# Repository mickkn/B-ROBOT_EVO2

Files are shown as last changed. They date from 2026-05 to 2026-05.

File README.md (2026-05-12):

# RCBRO - RC Based Self Balancing Robot

Based on this project:  
[Github](https://github.com/jjrobots/B-ROBOT_EVO2)  
[Thingiverse](https://www.thingiverse.com/thing:2306541)

# Introduction

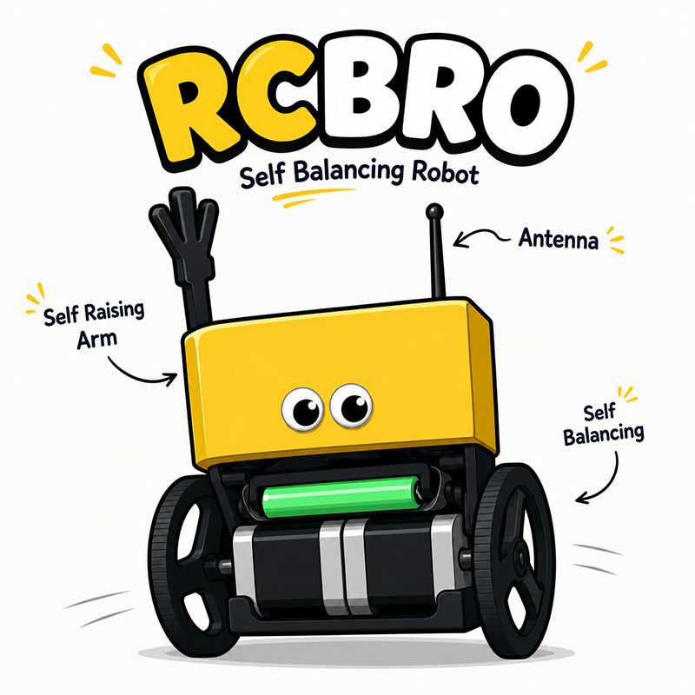
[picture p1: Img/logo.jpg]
RCBRO


RCBRO is a Radio Control Based Self Balancing Robot. It is a two-wheeled robot that can balance itself using a 
gyroscope and accelerometer. The robot can be controlled using a PWM based RC transmitter, allowing it to move forward, backward, turn and raise.

This project is designed around the Teensy 2.0 board, which feature a ATMega32U4 microcontroller. The Teensy 2.0 is a powerful 
and versatile microcontroller that is well-suited for robotics projects. It has a built-in USB interface, which allows for 
easy programming and communication with the robot.

## Pinout
The pinout for the Teensy 2.0 board is as follows:

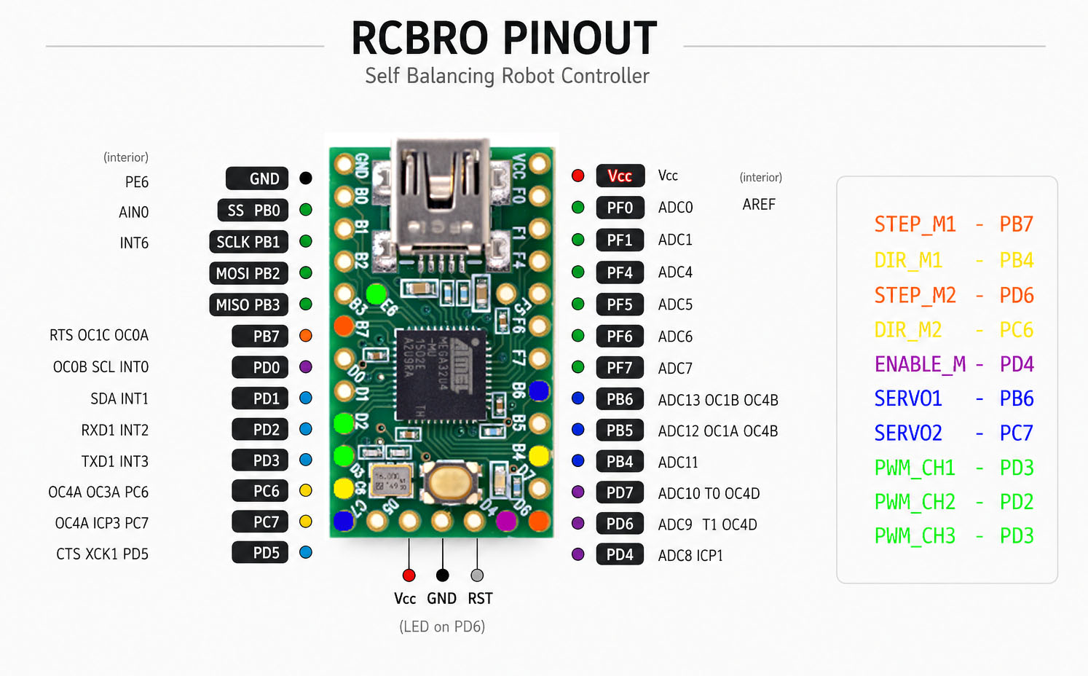
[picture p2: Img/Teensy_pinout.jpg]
Teensy 2.0 pinout


PD0 and PD1 are used for the I2C communication with the MPU6050 IMU sensor.

# Transmitter

The RC transmitter used in this project is a 3-channel FlySky FS-GT3B transmitter. It operates on the 2.4GHz 
frequency and has a range of up to 500 meters. The transmitter has a built-in LCD screen that displays the current 
channel and battery status.

The transmitter is flashed with [Custom Firmare 0.6.1](https://github.com/semerad/gt3b/tree/master) (or [0.6.2](RC)), which allows 
for better control and customization of the transmitter. 
The custom firmware also allows for the use of additional channels, which can be used for controlling additional features of the robot.

Newer versions of the transmitter has to be tweaked a little to be able to bind with the receiver. Check the RC folder for more details.

## RC Channel Mapping

| Channel | Pin (Teensy 2.0) | Function |
|---|---|---|
| CH1 | D3 (INT3) | Steering |
| CH2 | D2 (INT2) | Throttle |
| CH3 | E6 (INT6) | ARM (high) / PRO toggle (low) |

### CH3 functions
- **≤ 1200 µs** — Toggle PRO mode on/off (edge triggered)
- **~1500 µs** — Normal operation
- **≥ 1800 µs** — Activate servo arm

### CH3 Configuration
To configure CH3 for the desired functions (ARM and Pro-mode toggler).

Check the manual for more details: [FlySky FS-GT3B Custom Firmware Manual](RC/gt3b_fw_manual.pdf)

1. Choose REV and Long press the ENTER button.
2. Choose 3 CH3
3. Behavior: BMO (Behavior Mode - Momentary)
4. Reverse: RE0 (Reverse Off)
5. Previous Value: PV0 - No change in function

## Tuning

Key parameters in `RCBRO.ino` to tune for your build:

| Parameter | Description | Adjust if... |
|---|---|---|
| `MAX_THROTTLE` | Max speed in normal mode | Robot tips at full speed → lower it |
| `MAX_TARGET_ANGLE` | Max lean in normal mode | Robot tips at full speed → lower it |
| `MAX_THROTTLE_PRO` | Max speed in PRO mode | Same as above, for PRO |
| `MAX_TARGET_ANGLE_PRO` | Max lean in PRO mode | Same as above, for PRO |
| `ANGLE_OFFSET` | Balance trim | Robot drifts forward/backward at rest |
| `KP` / `KD` | Balance PD gains | Robot oscillates (lower) or sluggish (raise) |
| `KP_THROTTLE` / `KI_THROTTLE` | Speed PI gains | Speed response too slow / too aggressive |
| `MAX_ACCEL` | Motor acceleration limit | Motors skip steps (lower) or response is slow (raise) |
| `EXPO_STEERING` / `EXPO_THROTTLE` | Stick expo (0=linear, 1=cubic) | Centre feel too twitchy or too soft |

# Ideas

Use it for speed, fighting or whatever you want.

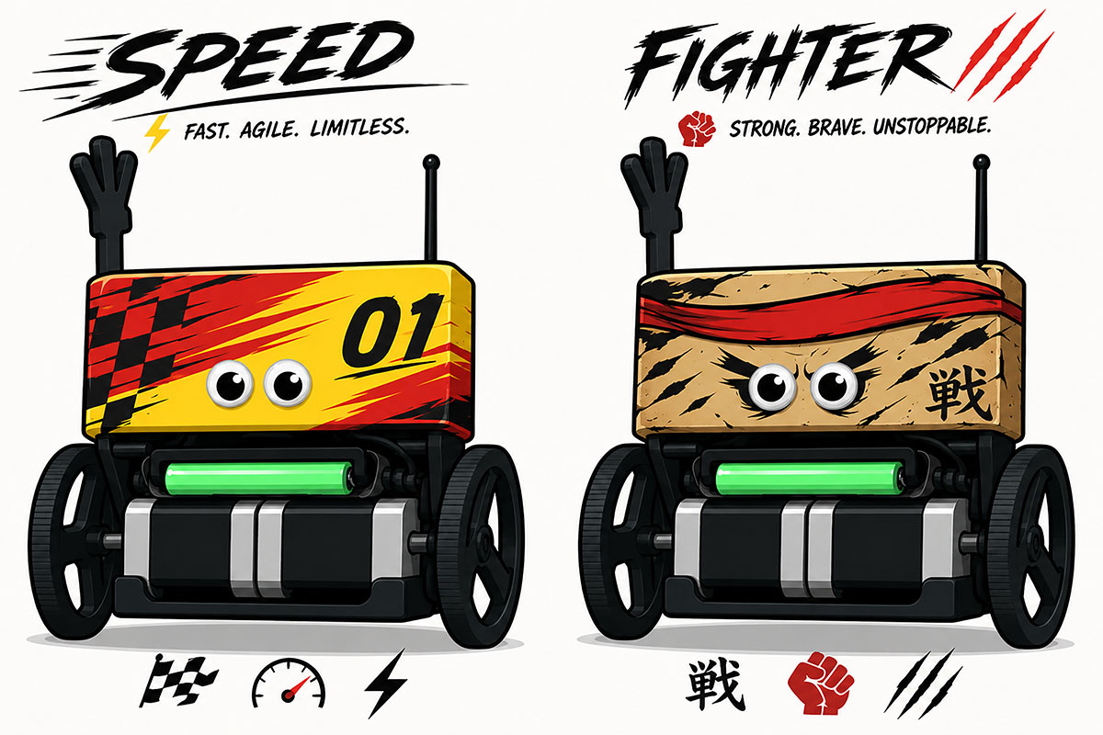
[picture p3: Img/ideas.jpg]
Ideas


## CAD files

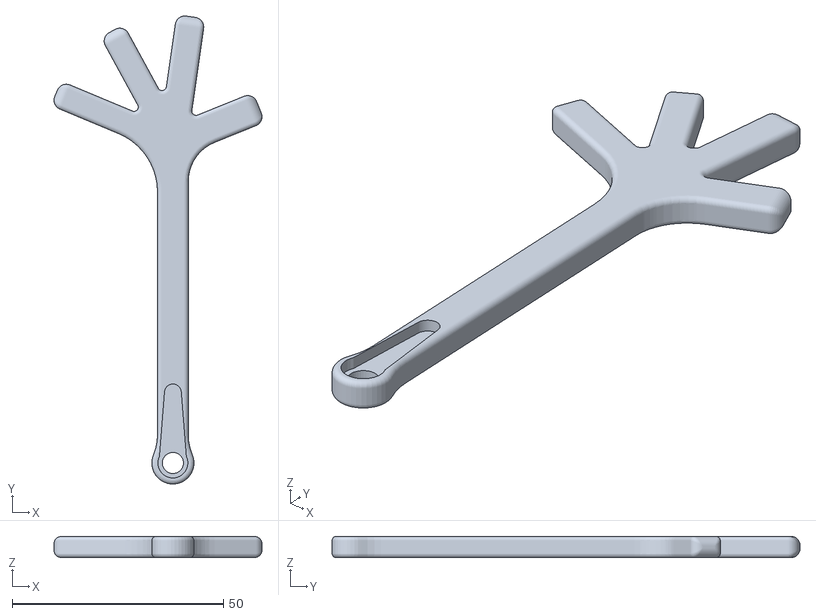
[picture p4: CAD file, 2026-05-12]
3D/Arm.STL
49.3 x 110.9 x 5.00

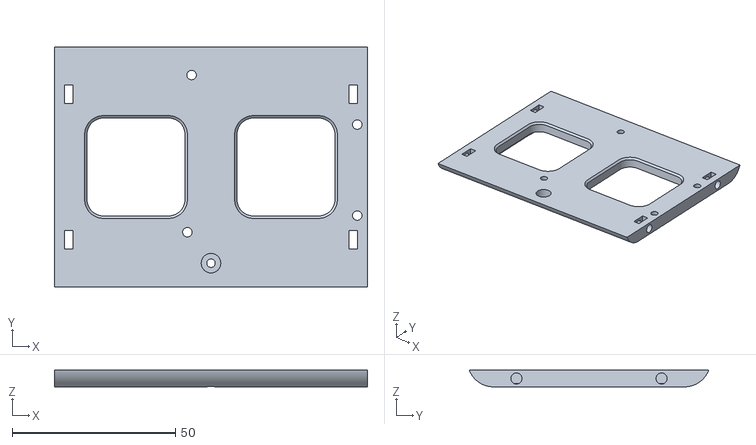
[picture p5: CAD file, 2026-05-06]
3D/Electronics_Shelf.STL
96.0 x 73.5 x 5.15

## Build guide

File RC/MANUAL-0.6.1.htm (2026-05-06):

Skip to content

Open menuHomepage (g then d) gGthen dD

Type / to search

Search or jump to…(forward slash) forward slash/

Chat with Copilot

Create new...

All issuesAll pull requestsAll repositories

You have no unread notifications(g then n) gGthen nN

Mick K Open user navigation menu

## Repository navigation

# Search code, repositories, users, issues, pull requests...

Search

Search syntax tips (https://docs.github.com/search-github/github-code-search/understanding-github-code-search-syntax)

Give feedback

# Provide feedback

We read every piece of feedback, and take your input very seriously.

Include my email address so I can be contacted

Cancel Submit feedback

# Saved searches

## Use saved searches to filter your results more quickly

Name

Query

To see all available qualifiers, see our documentation (https://docs.github.com/search-github/github-code-search/understanding-github-code-search-syntax).

Cancel Create saved search

Dismiss alert

Open in github.dev Open in a new github.dev tab Open in codespace

## FilesCollapse file tree

## Files

master

Search this repository(forward slash) forward slash/

tT

/

# MANUAL-0.6.1.txt

Copy path

Blame

More file actions

Blame

More file actions

## Latest commit

## History

History

History

430 lines (388 loc) · 17.7 KB

/

# MANUAL-0.6.1.txt

Top

## File metadata and controls

- Code
- Blame

430 lines (388 loc) · 17.7 KB

Raw (https://github.com/semerad/gt3b/raw/refs/heads/master/Releases/MANUAL-0.6.1.txt)

Copy raw file

Download raw file

Fork this repository and edit the file

More edit options

Open symbols panel

Edit and raw actions

1

2

3

4

5

6

7

8

9

10

11

12

13

14

15

16

17

18

19

20

21

22

23

24

25

26

27

28

29

30

31

32

33

34

35

36

37

38

39

40

41

42

43

44

45

46

47

48

49

50

51

52

53

54

55

56

57

58

59

60

61

62

63

64

65

66

67

68

69

70

71

72

73

74

75

76

77

78

79

80

81

82

83

84

85

86

87

88

89

90

91

92

93

94

95

96

97

98

99

100

101

102

103

104

105

106

107

108

109

110

111

112

113

114

115

116

117

118

119

120

121

122

123

124

125

126

127

128

129

130

131

132

133

134

135

136

137

138

139

140

141

142

143

144

145

146

147

148

149

150

151

152

153

154

155

156

157

158

159

160

161

162

163

164

165

166

167

168

169

170

171

172

173

174

175

176

177

178

179

180

181

182

183

184

185

186

187

188

189

190

191

192

193

194

195

196

197

198

199

200

201

202

203

204

205

206

207

208

209

210

211

212

213

214

215

216

217

218

219

220

221

222

223

224

225

226

227

228

229

230

231

232

233

234

235

236

237

238

239

240

241

242

243

244

245

246

247

248

249

250

251

252

253

254

255

256

257

258

259

260

261

262

263

264

265

266

267

268

269

270

271

272

273

274

275

276

277

278

279

280

281

282

283

284

285

286

287

288

289

290

291

292

293

294

295

296

297

298

299

300

301

302

303

304

305

306

307

308

309

310

311

312

313

314

315

316

317

318

319

320

321

322

323

324

325

326

327

328

329

330

331

332

333

334

335

336

337

338

339

340

341

342

343

344

345

346

347

348

349

350

351

352

353

354

355

356

357

358

359

360

361

362

363

364

365

366

367

368

369

370

371

372

373

374

375

376

377

378

379

380

381

382

383

384

385

386

387

388

389

390

391

392

393

394

395

396

397

398

399

400

401

402

403

404

405

406

407

408

409

410

411

412

413

414

415

416

417

418

419

420

421

422

423

424

425

426

427

428

429

430

****************************

* *

* Flysky GT3B/C-PSX manual *

* *

****************************

This is a preliminary manual for alternative firmware for FlySky FS-GT3B/C radio

and clones. This manual is written as differences to original firmware.

This firmware is completely written from scratch and is not compatible with the

original Flysky firmware. It is distributed with NO-WARRANTY.

All of the model setups saved by original firmware will be erased!!!

You can backup your original firmware and config, use tabs "PROGRAM MEMORY" and

"DATA MEMORY" in STVP to read it from radio a save it to disk.

Flashing firmware

=================

- uset STVP (ST Visual Programmer)

- select "PROGRAM MEMORY" tab

- load firmware "gt3b-VERSION.s19"

- program it with "Program -> Address Range..."

- set "Start @" to "8000"

- set "End @" to "E861" (it is possible to find place where zeroes

will start and use last non-zero address)

- press "OK"

- if "Program -> Current tab" will be used, all models stored at FLASH

will be erased

Global characteristics:

=======================

- 63 model memories, first 8 in EEPROM, rest in FLASH

> numbers 10-19 will show with Right-Arrow

> numbers 20-29 will show with Left-Arrow

> numbers 30-39 will show with Left+Right-Arrows

> numbers 40-79 will show like 0-39 with additional Percent symbol

- added Subtrims

- added SaveAs to save model config to another memory location

- added Global Setup menu to change function features, including backlight time,

battery low voltage, etc.

- dead zone for steering and throttle

- added key mapping specific for each model memory

- calibrate menu will be automatically invoked after first power-on with

this firmware, so 6 menu items will start to blink

- when radio is powered on with steering/throttle not in dead center,

it beeps 3 times if poweron not-centered warning is allowed

- added inactivity alarm

- added settable servo speed

- added 4WS, DIG, MultiPosition functions

- added timers (up, down, lap, lap count)

Buttons:

========

- it is now possible to differentiate between long press (>1 second) to

normal button press (short) and it will be recognized like "ENTER-long"

- Trims, DualRate and other popup informations

> now shows changed value only temporaly (5 seconds or till another

key press), values are saved to EEPROm automatically when it disappears

> when autorepeat disabled on trims (default), reset trim to 0

by pressing both trim keys together for long

(eg. TRIM_LEFT-long + TRIM_RIGHT-long and similar for channel 2 trim)

> while value is showed, it is possible to change it with rotate

encoder also

> when value set to reset_value (usualy 0), longer beep sounds to

attention to it and short pause is intruduced to ignore keys

Main screens:

=============

- changeable by rotate encoder:

model name

battery voltage

timer1 - ENTER and ENTER-long operates this timer, not standard menu

timer2 - ENTER and ENTER-long operates this timer, not standard menu

Standard menu:

==============

- swapped behaviour of ENTER and END when editing items, ENTER now select

next value and END (+ ENTER-long) will end editing items

- ENTER-long on ABS will leave menu also (as BACK)

- Trims are now only for steering and throttle

> trim move center position without moving endpoint positions

- Expo

> value for channel 2 is splitted to forward and back and is indicated

by arrows

> positive values are those You want to use like at Spektrum radios

- DualRate

> value for channel 2 is splitted to forward and back and is indicated

by arrows

- SaveAs

> choose menu MODEL and press ENTER-long

> menu MODEL will blink

> choose memory position where to save model config

> press ENTER/BACK to save it

- Model number of channels and Model reset

> choose menu NAME and press ENTER-long

> menu NAME will blink

> choose "C" for number of model channels or "r" for model reset

- reset will show NO/YES

- Subtrims

> subtrim moves center position together with endpoint positions

> choose menu TRIM and press ENTER-long

> menu TRIM will blink

> set subtrims for each channel

- channel speed

> choose menu D/R and press ENTER-long

> menu D/R will blink

> select channel

> for channels 1 and 2 (steering and throttle)

- turn wheel left to show left arrow

- this represents Turn speed or throttle speed

- turn wheel right to show right arrow

- this represents Return speed or

"throttle speed only for forward" (OFF/ON)

> select required speed 1...100%

- 100% means no delay

- 1% means above 4s delay end to end

- directly setting channel value of channels 3..8

> values for 4WS and DIG channels cannot be changed

> this can be used instead of mapping some key to appropriate function

> choose menu EXPO and press ENTER-long

> menu EXPO will blink

> select channel and press ENTER

> select value in range -100..100 and press enter

- mixes 4WS, DIG, throttle brake cut-off (for boats with forward-only

throttle), Multi-Position (to set arbitrary up to 8 positions),

brake channel (to send brake side of throttle to extra channel)

> choose menu EPOINT and press ENTER-long

> menu EPOINT will blink

> select one of mixes 4WS (4), DIG (d), brake cut-off (b),

multi-position (P), brake channel (8)

for mixes 4WS, DIG:

> press ENTER and choose channel for this mix or OFF

- for dual-ESC steering (boat, tank, ...) select DIG channel 1 and

with steering D/R reduce required ESC travel (at 100% it will go to

contra to allow steering at place)

> press ENTER and set mix in range -100...0...100 %

0% is default and means both channels have same max steering/throttle

100% means 100% reduce on rear steering/throttle (eg. no steering)

-100% means 100% reduce on front steering/throttle (eg. no steering)

> for 4WS press ENTER and select crab (CR1) or no-crab (CR0)

for Multi-Position:

> there are 4 Multi-Positions identified by numbers 1..4, they have

8/6/4/4 positions

> press ENTER and choose channel for this function or OFF

- channel can be "D" also, which means map to DIG function

> press ENTER and set channel value for first position

> press ENTER and set channel value for second position or END

> ... up to eight position

for brake cut-off:

> press ENTER and choose OFF or CUT

for brake channel:

> press ENTER and choose channel fro brake or OFF

- Key mapping specific for each model:

> choose menu REV and press ENTER-long

> menu REV will blink

> choose trims (id: 1 2 3 d) or other keys (CH3: C, Back: b, End: E) or

if trim is OFF, then also trim keys (id 1 2 3 d with left/right arrow)

> press ENTER and modify first setting

> press ENTER and modify next setting

> ....

steps of settings of trims (1 2 3 and D/R):

- sequence:

function -> buttons -> step -> reverse -> opposite_reset -> previous_val -> rotate

- function: selected function listed at the end of manual

- B buttons:

MO - momentary, hold left/right trim key to get end values,

when nothing pressed, servo is at center

NL - no long keys, long press is the same as short press

AR - autorepeat is on

RS - long press of one of trim keys will reset to

centre/reset value

EN - long press of trim key will set to coresponding end value

- step: select trim step for one trim key press (1, 2, ... 100, 200),

not available when buttons MO or fuction is list of items (multi-position)

is identified by symbol "V"

- RE reverse:

0 - no change

1 - swap left/right trim keys

- OR opposite_reset: not available when buttons MO

0 - no change

1 - when trim key is pressed and value is at opposite

side of center/reset, set value to centre/reset,

- PV previous_val: available only when buttons MO or fuction is list of

items (multi-position)

0 - no change

1 - instead of setting value to centre/reset when key is released,

it is set to previous value, which was active before key press

- RO rotate: available only if fuction is list of items (multi-position)

0 - no rotate

1 - rotate from max item to first item and back

steps of setting of keys (C b E 1< 1> 2< 2> 3< 3> d< d>):

- sequence:

function -> momentary -> reverse -> prev_val -> function_long -> reverse_long -> prev_val_long

- function: selected function listed at the end of manual

- MO momentary: only available for 2-state functions (channel, ...)

0 - switch, key press will switch something (channel value, ...)

1 - momentary, value change will be active only while key is pressed

- RE reverse: only available for 2-state functions

0 - normal, no-press or default value is left endpoint

1 - reverse, no-press or default value is right endpoint

- PV prev_val: only available for 2-state functions

0 - key release or OFF state sets value to left endpoint (noREV)

1 - key release or OFF state sets value to value active before

key press or ON state

- function_long: function applied when long press of key happens,

choose from the same list as function,

identified by "V" symbol

- reverse_long: same as "reverse" + "V" symbol

- prev_val_long: same as "prev_val" + "V" symbol

steps of settings of ch3 potentiometer (if enabled at global config):

- sequence:

function -> reverse

- function: selected function listed at the end of manual

- RE reverse:

0 - no change

1 - swap left/right sides

Operating timers:

=================

- select timer1 or timer2 main screen with rotate encoder

- timer1 is identified by left arrow, timer2 by right arrow

- lap count is written to 3char LCD place

- timer value is writen to 7seg + 3char LCD place in format:

0000 - MMSS minutes, seconds

0000 % - SSHH seconds, hundredths (0.01 seconds)

- press ENTER to set timer params, use it as usual menu:

H set throttle trigger start OFF/ON

timer will start after

throttle forward applied

A set alarm 0..255

in laps for lap counter

in minutes for others

P set timer type:

OFF timer is off

UP up timer

TxS start/pause timer

TxR stop + reset timer

DWN down timer

TxS start/pause timer

TxR stop + reset timer and save rest time

to lap times

when alarmed at time 0, starts counting

up with "V" symbol blinking

LAP lap timer - 100 lap times are saved

TxS record lap time, show it for 3s blinking

and during this time presses are ignored

to eliminate double click

when timer not running, start timer

when timer alarmed, stop timer and save

lap time

TxR stop timer

LPC lap counter - till 255 laps

TxS increment lap counter, minimum 3 seconds

between presses are required to eliminate

double click

TxR zero lap counter

- pres ENTER-long to show saved lap times (only for LAP and DWN timers):

> It is possible to see lap number (indicated by 'L' at 7seg number)

or time showed as other timer values. Press ENTER to switch between

lap number and time value

> use rotate encoder to switch between lap numbers or lap times

> there are special lap number identificators also at 3char display:

- Txx - total time, 'xx' is number of laps

- Axx - average time, 'xx' is number of laps

- RES - pres ENTER and lap times will be erased, it is also

displayed when showing lap time

Calibrate menu:

===============

- enter it by wheel right-turn and ENTER-long

- 6 menu items starts to blink (+ 2 arrows if CH3 is potentiometer)

- use END or ROTATE to change channels

- there is also channel 3 representing CH3 button (for those who will do

some 3-position switch/potentiometer modification)

> There is 1K resistor connected between CH3 button and +5V, so

simply connecting linear potentiometer instead of CH3 button

will not work. Usefull results can be done with logarithmic

potentiometer 10K which has 1K at half of turn. Or eliminate

internal resistor to +5V, connect potentiometer between +5V

and GND and potentiometer output instead of CH3 button.

- there is also channal 4 representing battery voltage

- calibrate as usual (for channel 1/2 left+mid+right and ENTER)

> calibrated value will disappear from menu

> it is not needed to calibrate all values

- calibrate CH3 potentiometer (if selected at global config)

> only left + right positions

- calibrate battery (it will not be probably needed to use this)

> select channel 4

> press ENTER

> set your current battery voltage (measure it by voltmeter)

> press ENTER to save it or END to no-save

- press BACK-long or ENTER-long to end calibrate menu and save values

Key-test menu:

==============

- enter it by wheel left-turn and ENTER-long

- if ENTER-long keep pressed, all segments on display will stay on till

ENTER is released

- now check keys by pressing them short or long

- if keys long pressed, an "L" symbol will appear left to displayed key symbols

- press BACK-long or ENTER-long to end key-test menu

Global setup menu:

==================

- enter it by ENTER-long

- now menu items MODEL and NAME will start blinking

- select requested item by ROTATE and press ENTER

- use ROTATE to change value and press ENTER to end value changing

- press BACK or END or ENTER-long to end global setup menu,

values will be saved to EEPROM

- selected menu items are indicated by following symbols:

F firmware version (this of course cannot be changed :-)

L backlight time 5s,10s...10m...MAX

I inactivity alarm OFF,1m...10m

LOW POWER! battery low voltage 2.0...10.5V

C default number of channels 2..8

E maximum allowed endpoint value 100...150%

DANGER - values greater than 120% can damage

your servo or will not be possible

to transmit to receiver because of

2.4GHz HF module limitation

This danger zone will be indicated with a flashing

'%' symbol for values greater than 120%

A analog settings, dead zones, ADC samples used

steering dead zone S00..S50

throttle dead zone T00..T50

number of ADC values A_4/A_1

b beeps

key beep K_N/K_Y

value at center/reset beep V_N/V_Y

poweron beep P_N/P_Y

poweron not-centered warn C_N/C_Y

d long press key delay 100...1000 miliseconds

H setting of hardware features

reverse rotate encoder E_N/E_R (Normal/Reverse) - for GT3C

ch3 is potentiometer P3N/P3Y (No/Yes)

select ppm sync/frame PTS/PTF (constant SYNC/frame length)

select ppm length Lxx - 3-18ms for constant SYNC length

9-24ms for constant frame length

r global or all models reset

all configs (global+model) G_N/G_Y (No/Yes)

all models M_N/M_Y (No/Yes

o lock keys till ENTER-long No/Yes

Return to original (and modified) firmware:

===========================================

- flash original firmware

- delete whole EEPROM (tab DATA MEMORY in STVP and write those empty zeroes)

or return back your saved config (also tab DATA MEMORY in STVP, read

your saved config from disk and write it to radio)

- calibrate steering and throttle (not needed when You returned back saved

config)

Functions assignable to trims:

==============================

OFF - nothing, it is possible to assign each button individualy

as key

TR1, TR2 - trim of channel 1/2

DRS, DRF, DRB - dualrate of steering/forward/back

EXS, EXF, EXB - expo of steering/forward/back

CHn - change channel "n" value in range -100...100

STn - subtrim of channel "n"

SST - steering speed turn 1...100%

SSR - steering speed return 1...100%

CSn - channel speed for channel "n" 1...100%

4WS - 4 wheel steering mix -100...100%

DIG - DIG throttle mix -100...100%

MP1 - Multi-Position 1, switches position up/down

MP2 - Multi-Position 2, switches position up/down

MP3 - Multi-Position 3, switches position up/down

MP4 - Multi-Position 4, switches position up/down

Functions assignable to keys:

=============================

OFF - nothing

CHn - switch channel "n" value from one end value to opposite end

value. There is special handling for CH3 button. When using

3-position switch instead of CH3 button and momentary is

selected for this button, then centre 3-pos value will also

be detected and set to servo (use 1K resistor to GND to get

middle state)

CnR - reset value of channel "n" to centre

4WS - switch crab (CRB) no-crab (NOC) for 4 wheel steering

DIG - switch DIG mix between -100 and 100 (more useable when using

return to previous val key setting)

DGR - reset DIG mix to centre

MP1 - Multi-Position 1, switches position up (at END back to 1.)

MR1 - Multi-Position 1 Reset, switches position to first one

MP2 - Multi-Position 2, switches position up (at END back to 1.)

MR2 - Multi-Position 2 Reset, switches position to first one

MP3 - Multi-Position 3, switches position up (at END back to 1.)

MR3 - Multi-Position 3 Reset, switches position to first one

MP4 - Multi-Position 4, switches position up (at END back to 1.)

MR4 - Multi-Position 4 Reset, switches position to first one

T1S - start/pause timer1

T1R - stop + reset timer1

T2S - start/pause timer2

T2R - stop + reset timer2

BRK - switch on full brake, this overrides throttle position

BLS - battery low shutup, stop beeping, predefined to END-long

## Footer

(https://github.com) © 2026 GitHub, Inc.

You can’t perform that action at this time.

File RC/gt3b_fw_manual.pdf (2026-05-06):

# PSX Firmware for Flysky GT3B/C Manual

# https://github.com/semerad/gt3b/tree/master/Releases

Gerry Holm
1/29/2013

## Contents

## 1. Parts of the Transmitter

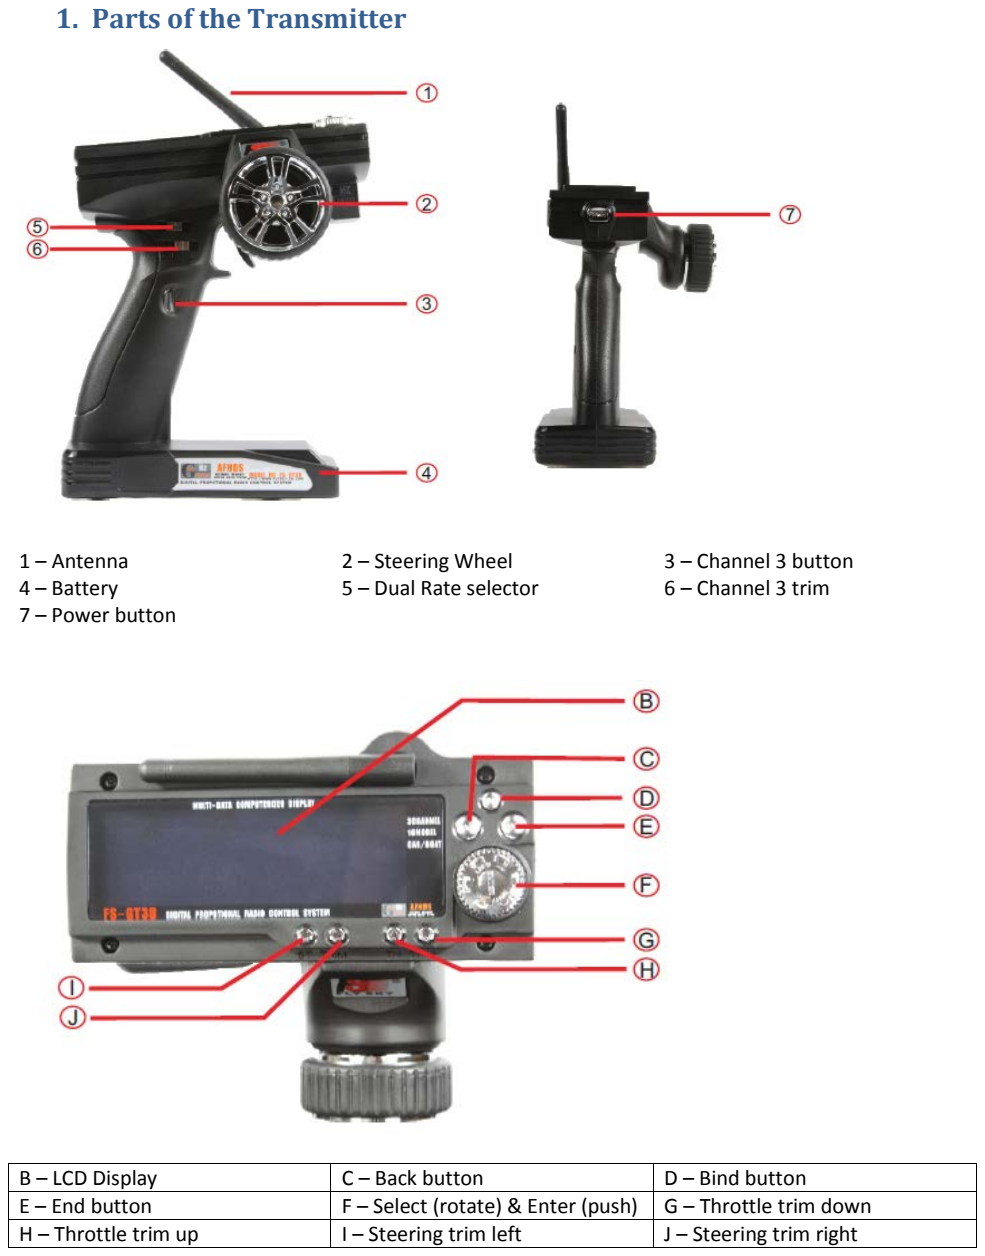
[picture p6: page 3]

1 – Antenna | 2 – Steering Wheel | 3 – Channel 3 button
4 – Battery | 5 – Dual Rate selector | 6 – Channel 3 trim
7 – Power button
B – LCD Display | C – Back button | D – Bind button
E – End button | F – Select (rotate) & Enter (push) | G – Throttle trim down
H – Throttle trim up | I – Steering trim left | J – Steering trim right

## 2. Binding a receiver to the radio

The following steps can be used to bind or match a receiver to the radio. The radio needs batteries and the receiver needs to be connected to an ESC or a battery. If using a battery do not connect the battery to the receiver until instructed. Start with the radio and receiver off.

1. Insert the binding plug to the BIND/ CH3 port on the receiver (see figure 1)
2. If using a battery connect it to the VCC port of the receiver, otherwise turn on the ESC
3. The receiver’s LED should be flashing. This means the receiver is in matching mode.
4. Press and hold the BIND button on the radio then turn the radio on. Continue to hold the BIND button.
5. Observe the LED on the receiver, if the receiver LED stops flashing that indicates the receiver has been bound to the radio. This may take several seconds.
6. Release the BIND button, turn off the receiver and the radio, remove the binding plug.

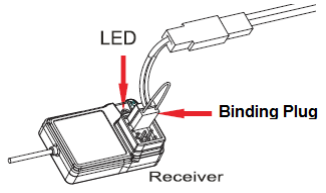
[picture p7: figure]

Figure 1

## 3. LCD Display

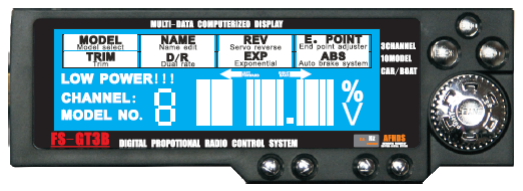
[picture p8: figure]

Figure 2
Button Functions:

Turn the ENTER button clockwise to increase the rate or to move the selection to the right
Turn the ENTER button counterclockwise to decrease the rate or to move the selection to the left Press ENTER to select an item
Press BACK to return to the Home screen
Press END to return to the previous menu

Pressing a button for more than 1 second if referring in this document as a long key press. For example, pressing and holding the ENTER button is referred to as ENTER-LONG

### 3.1 Power on display

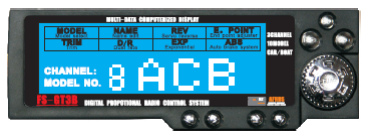
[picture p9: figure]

When the radio is initially turned on, it displays the current model number along with the name assigned to it. For reference the left digit (shown as 8 in the picture above) is referred to the number display and the 3 characters (shown as ACB) is referred to as the alphanumeric display.

This screen is referred to as the Home screen. Only the model number and name are displayed.

If the battery voltage of the radio is lower than the low power voltage threshold (see Global setup menu), the radio will beep and LOW POWER! will be blinking as can been seen in figure 2.

Rotating the SELECT, will move between the model number, the battery voltage and the 2 timers (indicated by the Left/Forward arrow or the Right/Back arrow (see section 3.3 Timers).

### 3.2 Models

As of version 0.6.1 of the firmware, the radio is capable of 63 model memories. The first 8 models are stored in EEPROM and the rest in Flash.

- Models 10-19 will show with Right/Back arrow
- Models 20-29 will show with Left/Forward arrow
- Models 30-39 will show with Left and Right arrow
- Models 40-79 will show like 0-39 but with the addition of the % symbol.

To select a model, you must be at the home screen with just the model number and name displayed or on the battery voltage display. Press ENTER and Model will be highlighted. Press ENTER again and the model number will flash. Rotate SELECT to change the model selection, then press ENTER.

### 3.3 Timers

There are 2 built in timers that can be viewed from the Home screen. To access the timers, rotate SELECT. Timer 1 is indicated by the Left/Forward arrow and Timer 2 is indicated by the Right/Back arrow.

The timers can provide a lap counter, lap timer, count up timer or count down timer. For the lap functions these are displayed on the alphanumeric display. Time is displayed in two ways. For time under 100 seconds, the display will show % and the time will be represented by 4 digits. The first 2 digits the seconds and the last 2 digits the hundredths of seconds.

Timers are operated by programming buttons on the radio to start, stop and reset the timer. These buttons are specific to the model that’s selected, so it’s important to remember that programming a button to start the timer must be done for each model. For reference the button assigned to start a timer is referred to TxS where x is the timer number. TxR is the timer reset. See section 4.14 Key Mapping for more information.

To set the options for the timers, select the timer then press ENTER. The following are options for each timer. The option is selected when the number display is flashing by rotating SELECT. To change the value, press ENTER and rotate SELECT to select the value for that option. Pressing ENTER to return to the option selection.

Option | Parameters
H – Start the timer when the throttle is applied. Useful for starting a timer at the beginning of a race. | On or Off
A – Set an alarm. When the alarm value is reached, the radio beeps | For lap functions, the number of laps. For time functions the number of minutes
P - Timer type | OFF – Timer is off UP – Up timer TxS will start/pause the timer, TxR will stop and reset it. DWN – Down timer. The timer will start at the value set on the alarm option. When the timer reaches 0, the radio will beep, a V will displayed and the timer will start counting up. LAP – Lap timer (up to 100 lap times). TxS will record the lap time which flash on the display for 3 seconds. TxR will stop the timer (this does not record a lap time). If an alarm is set the timer will automatically stop when that time is reached. LPC – Lap counter (up to 255 laps). TxS counts a lap. There is a minimum of 3 seconds between laps to eliminate accidental double counts. TxR resets the counter

For the lap timer, it’s possible to view the saved lap times once the timer has stopped. To view the lap times, press ENTER-LONG. This will bring you to the Lap menu which is indicated by an L in the number display. Different display functions can be reached by rotating SELECT.

L RES – Reset, any time RES is displayed, pressing ENTER will erase all lap information and take you back to the timer screen.

L T – Displays the number of laps. Pressing ENTER will display the total time recorded by laps (not the total time the timer ran). Rotating SELECT will show you the times of the laps. Pressing ENTER on any display other than RES takes you back to the Lap menu.

L A – Displays the number of laps. Pressing ENTER, will display the average lap time. Rotating SELECT shows you the same total time and lap time information at above. Pressing ENTER on any display other than RES takes you back to the Lap menu.

L # - Allows you to select a specific lap. Pressing ENTER will display the lap time for this lap. Rotating SELECT changes the lap selection and will show you the total time as above. Pressing ENTER on any display other than RES takes you back to the Lap menu.

## 4. Model Settings

Each model memory can have a wide range of settings specific to that model. To access these settings press ENTER from the Home screen.

### 4.1 Model Name

This function allow you to assign a 3 digit name (letters and numbers) to the selected model. To set the model name rotate SELECT until NAME is highlighted and press ENTER.

Rotate SELECT to select the value for that digit and press ENTER to move to the next digit. Pressing END takes you back to the menu selection and pressing BACK takes you back to the Home screen.

### 4.2 Copy Model Settings

Copy model settings allows you to copy all the settings of one model memory to another. First select the model to copy (see section 3.2). To copy rotate SELECT until MODEL is highlighted and press ENTER-LONG. The menu MODEL will be blinking. Rotate SELECT again to choose the model memory position to copy to and press ENTER or BACK to save it.

### 4.3 Reverse

This function reverses the direction of the operation of the servos. For example, turning the radio’s steering wheel to the left causes the vehicles wheels to turn right needs to have the steering servo reversed.

Each channel can have either a setting of Normal which is displayed as NOR or Reverse which is displayed as REV.

To change the server reverse settings, from the Home screen, press ENTER to access the menu, and rotate SELECT until REV Servo Reverse is highlighted and press ENTER. The channel number will blink. You select the channel you want to change by rotating SELECT then pressing ENTER. Rotate SELECT to select the setting. Pressing ENTER will take you back to the channel selection.

### 4.4 End Points

End points allow independent travel adjustment of the servo throw in each direction of all channels (steering, throttle, etc). They can also be used to limit the amount of throttle or brake applied through an electronic speed control.

The default maximum end point is 120%. This value can be changed in the Global setup menu (see…).

To change end points, from the Home screen press ENTER and rotate SELECT until E. POINT is highlighted and press ENTER. The channel number will blink. You select the channel you want to change by rotating SELECT then pressing ENTER.

Once the end point value is flashing, you can set the value for Left/Forward or Right/Back is indicated by the arrow above it. To set the end point rotate SELECT. A higher value means more servo throw and a lower value means less. You select the Left/Forward or Right/Back portion of the setting by moving the steering wheel or throttle in the appropriate direction.

Once the settings for that channel have been made, press ENTER to return to the channel selection.

### 4.5 Trims

Trims are used to adjust the neutral position of steering, throttle, etc.

Trims can be set either using the various trim buttons on the radio or by accessing the TRIM menu.

A trim can be reset to 0 via the trim buttons by pressing and holding both trim buttons for 1 second.

To change end points via the TRIM menu, from the Home screen press ENTER and rotate SELECT until TRIM is highlighted and press ENTER. The channel number will blink. You select the channel you want to change by rotating SELECT then pressing ENTER. Once the trim value is flashing, you can set the value rotating SELECT.

Once the settings for that channel have been made, press ENTER to return to the channel selection.

### 4.6 Sub Trims

The Sub Trim function is normally used to correct for minor angular inaccuracies that occur when placing the servo horn on the servo. In many cases, the servo horn is not exactly perpendicular to the servo (or in the exact optimum desired position). Minor sub trim values can be used to correct this offset inaccuracy, however, it’s important to understand that large sub trim values can limit the total throw of the servo in that direction so small sub trim values only are recommended along with adjusting the placement of the servo horn.

To change the sub trims, from the Home screen press ENTER and rotate SELECT until TRIM is highlighted and press ENTER-LONG. TRIM and the channel number will blink. You select the channel you want to change by rotating SELECT then pressing ENTER.

Change the sub trim value for that channel by pressing ENTER. Pressing ENTER will return you to the channel selection.

### 4.7 Dual Rates

Dual rates or D/R limit the total travel of each individual channel in equal amounts in both directions. Adjustments can be made between 100% (full servo travel) and 0% (no servo travel).

By default the steering D/R can be adjusted using the D/R selector on the radio’s grip. D/R can also be adjusted via the D/R menu.

To change the dual rate via the D/R menu, from the Home screen press ENTER and rotate SELECT until D/R is highlighted and press ENTER. The channel number will blink. You select the channel you want to change by rotating SELECT then pressing ENTER. Once the D/R value is flashing, you can set the value rotating SELECT.

The dual rate for channel 2 (throttle) has separate values for forward and back. If channel 2 is selected, separate dual rates can be selected as indicated by the arrows above the D/R value. To change between forward and back, use either the steering wheel or throttle.

Once the settings for that channel have been made, press ENTER to return to the channel selection.

### 4.8 Expo

Exponential or Expo for short, is used to affect the response rate of the steering, throttle and/or brake. Typically positive Expo is used for steering, reducing steering sensitivity around neutral, making it easier to drive the car at high speeds in a straight line but exponential still allows for the maximum turning radius.

Positive and negative Expo values are available. A positive Expo value results in the center being less sensitive (desirable most of the time) while a negative value increases the sensitivity around center (normally not used).

To change exponential, from the Home screen press ENTER and rotate SELECT until EXP is highlighted and press ENTER. The channel number will blink. You select the channel you want to change by rotating SELECT then pressing ENTER. Once the Expo value is flashing, you can set the value rotating SELECT.

Exponential for channel 2 (throttle) has separate values for forward and back. If channel 2 is selected, separate exponential rates can be selected as indicated by the arrows above the EXP value. To change between forward and back, use either the steering wheel or throttle.

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

### 4.9 ABS

When applying the brakes, it’s possible to lock them which can cause your vehicle to spin out of control. This can be eliminated by pulsing the brakes, so that better control can be archived. The ABS function of the radio operates in a similar fashion to the ABS brakes on a real car, where the application of brakes is pulsed.

To change ABS, from the Home screen press ENTER and rotate SELECT until ABS is highlighted and press ENTER. Channel 2 will blink since it’s only possible to apply ABS to the throttle. Select the ABS value by rotating SELECT. There are 4 possible ABS settings:
OFF – The ABS function is off
SLW – Slow pulse
NOR – Normal pulse
FST – Fast pulse

Each car and ESC/braking servo responds differently to different ABS settings.

### 4.10 Channel Speed

Channel speed controls the rate the radio sends the receiver commands to go from neutral to full (and everything in between). Channel speed can’t make them faster, only slower. It’s most useful to control throttle and brake when the vehicle itself lacks methods to control these. Using channel speed on steering in not common.

To change channel speed, from the Home screen press ENTER and rotate SELECT until D/R is highlighted and press ENTER-LONG. D/R and channel number will blink. You select the channel you want to change by rotating SELECT then pressing ENTER. Once the channel speed value is flashing, you can set the value rotating SELECT.

The speed is entered as a percentage of full speed. A setting of 100% means no delay, while a setting of 1% is about a 2 second delay from neutral/center to full.

Channel speed has separate values, indicated by the arrow above the value. This can be selected by turning the steering wheel or moving the throttle.

Channel 1 & Left Arrow: Turn speed
Channel 1 & Right Arrow: Steering return to center speed
Channel 2 & Right Arrow: Throttle speed
Channel 2 & Left Arrow: Brake speed

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

### 4.11 Direct Channel Value

Direct channel value, allows you to set a specific value for channels 3-8 when activated. When this value is set, there are only 2 states for that channel, off/neutral or on at the value set. It is useful when you have a servo where the control is either centered or at a specific position (not necessarily full).

To change the channel value, from the Home screen press ENTER and rotate SELECT until EXP is highlighted and press ENTER-LONG. EXP and the channel number will blink. You select the channel you want to change by rotating SELECT then pressing ENTER. Once the channel value is flashing, you can set the value between -100 and 100 by rotating SELECT.

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

### 4.12 Number of channels and Model reset

You can reduce the number of channels available to a specific model or reset all the settings of a specific model to their default values. You cannot set the number of channels higher than the firmware supports, even though this menu allows it.

From the Home screen press ENTER and rotate SELECT until NAME is highlighted and press ENTER-LONG. Name will blink. You select the option you want to change by rotating SELECT then pressing ENTER. The parameter for the option is set by rotating SELECT. Press ENTER to return to the option selection.

C – Number of channels
r – Reset model settings (Select Yes to confirm or No to cancel)

### 4.13 Channel mixes

This section needs to be completed.

### 4.14 Button Mapping

Each model can have the buttons of the radio assigned to a specific function that varies from the default.

To access the button mapping menu, from the Home screen press ENTER and rotate SELECT until REV is highlighted and press ENTER-LONG. The REV menu will flash indicating you are in the button mapping menu.

The number display shows the button being programed and the alphanumeric display will show the function currently assigned to that button. There are 2 types of buttons, trim buttons and regular buttons. Additionally, individual Trim buttons can be mapped to specific functions. Table 4.14 lists the buttons on the radio and the display code for that button:

### Table 4.14

Display | Button(s) on radio | Type
1 | Steering trim | Trim
2 | Throttle trim | Trim
3 | Ch3 Trim | Trim
d | D/R buttons | Trim
C | Ch3 button | Regular
b | Back button | Regular
E | End button | Regular
1← | ST Trim Left | Regular*
1→ | ST Trim Right | Regular*
2← | TH Trim Back (Throttle) | Regular*
2→ | TH Trim Forward (Brake) | Regular*
3← | Ch3 Trim Back | Regular*
3→ | Ch3 Trim Forward | Regular*
d← | D/R - | Regular*
d→ | D/R + | Regular*
* Only available when the setting for that specific trim button is set to off.

### 4.14.1 Mapping Trim Buttons

Trim buttons can be assigned the functions listed in Table 4.14.1 below.

### Table 4.14.1

Option | Function
OFF | Turn normal trim function off. Turns on programming of individual trim buttons
TR1, TR2 | Normal trim function channel 1/2
DRS, DRF, DRB | Dual Rate of Steering/Forward/Brake
EXS, EXF, EXB | Expo of Steering/Forward/Brake
CHn | Change channel “n” to value in range -100 to 100
STn | Subtrim channel “n”
SST | Steering speed turn 1% to 100%
SSR | Steering speed return to center 1% to 100%
CSn | Channel Speed for channel “n” 1% to 100%
4WS | 4 Wheel Steering Mix -100% to 100%

DIG | DIG Throttle mix -100% to 100%
MPn | Multi-Position “n”, switches position up/down

The mapping sequence for all settings other than OFF is:
Function → Button Option → Step¹ → Reverse → Opposite Reset² → Previous Value¹ → Rotate³
1 – Not available when Button Option set to MO or function is set to Multi-Position
2 – Not available when Button Option set to MO
3 – Only available if function is set to Multi-Function
Button Options, controls the effects of pressing and holding a button:
BMO – Momentary, holding trim button sets the value of the function to it’s minimum (left trim button) or maximum (right trim button). When neither button is pushed, value is default.
BNL – No Long button, disables long button presses
BAR – Auto repeat is on
BRS – Long press of one trim button resets to center/neutral value
BEN – Long press of trim key will set the value to maximum in that direction

Step (indicated by the symbol “V”), selects the number of trim steps for every button press. Not available when Button Option is set to BMO or Function is set to Multi-Position.

Reverse:
RE0 – Normal trim direction
RE1 – Swap left and right trim buttons

Opposite Reset:
OR0 – Normal trim operation, each button press increases or decreases it’s value
OR1 – When trim button is pressed and the current value is opposite of center/neutral of the button being pushed, set the value to center/neutral. For example if the steering trim is currently R5, pressing the Left Steering Trim will set the steering trim to center.

Previous Value:
PV0 – No change in function
PV1 – Instead of setting value to center/neutral when button is released, it is set to the previous value, the value the function had before the button was pressed.
Rotate:
RO0 – No rotation
RO1 – Rotate from max item to first item and back

### 4.14.2 Mapping Normal Buttons

Normal buttons can be assigned the functions listed in Table 4.14.2 below.

### Table 4.14.2

Option | Function
OFF | Turns button off
CHn | Switch channel “n” value from one end value to opposite end value

CnR | Reset value of channel “n” to center/neutral
4WS | Switch between crab (CRB) and no-crab (NOC) for 4 wheel steering
DIG | Switch DIG mix between -100 and 100. Most useful when used with the return to previous value key setting
DGR | Reset DIG mix to center
MPn | Multi-Position “n”, switches position up
MRn | Multi-Position “n”, switches position to first one
T1S, T2S | Start and Pause Timer 1/2
T1R, T2R | Stop and reset Timer 1/2
BRK | Switch on full brake, overrides throttle position
BLS | Turn off Battery Low Voltage alarm (predefined as END-LONG)

The mapping sequence for all settings other than OFF is:
Function → Momentary¹ → Reverse¹ → Previous Value¹ → Function-Long → Reverse-Long → Previous Value-Long
1 – Only available for 2 state functions
Function:
Desired function from table 4.14.2, when the button is pressed

Momentary, controls the effects of pressing button:
MO0 – Momentary off. Pressing the button, switches the values
MO1 – Momentary on. Pressing the button, switches the values only while the button is held

Reverse:
RE0 – Default value, no-press or default value is left endpoint
RE1 – Reverse value, no-presss or default value is right endpoint

Previous Value:
PV0 – Key release or OFF state set value to endpoint defined with Reverse (default is left endpoint)
PV1 –When button is released, it is set to the previous value, the value the function had before the button was pressed.

Function-Long:
Desired function from table 4.14.2, when the button is pressed and held for 1 second or longer. Identified by the symbol “V” displayed.

Reverse-Long:
Same settings as Reverse. . Identified by the symbol “V” displayed.

Previous Value-Long:
Same settings as Previous Value . Identified by the symbol “V” displayed.

## 5. Global Setup

To access the global setup menu, from the Home screen press ENTER-LONG. Menu items MODEL and NAME will blink. The option is selected when the number display is flashing by rotating SELECT. To change the value, press ENTER and rotate SELECT to select the value for that option. Press ENTER to return to the option selection.

Option | Parameters
F – Firmware version | Can’t be changed.
L – Backlight time, sets how long the backlight stays on after menu activity. | 5 seconds, 10 seconds,…1 minute…10 minute, MAX (never turn off)
I – Inactivity alarm in minutes. | OFF, 1m…10m
LOW POWER! – Voltage threshold before the radio sets the low power alarm | 2.0v to 10.5v
C – Default number of channels | 2 to 8
E – Maximum allowed endpoint value | 100-150%, DANGER - values greater than 120% can damage your servo or may not work because of limitations of the 2.4GHz hardware. A setting of more than 120% will result in a flashing % symbol.
A – Analog settings | S00-S50 – Steering dead zone T00-T50 – Throttle dead zone A_4/A_1 – Number of ADC (Analog to Digital) values to sample
b - Beeps | K_N/K_Y – Key press beep V_N/V_Y – Beep on trim values set to center/neutral or reset P_N/P_Y – Power on beep C_N/C_Y – Beep if wheel or throttle not centered when powered on
d – Long press key delay | 100-1000ms
H – Hardware features | E_N/E_R – Rotate encoder either Normal or Reverse (for GT3C) P3N/P3Y – Ch3 is potentiometer, No or Yes PTS/PTF – Select PPM Sync/frame Lxx – Select PPM length in ms. 3-18ms for constant SYNC length, 9-24ms for constant frame length
r – Reset | G_N/G_Y – Reset all radio settings and models to default M_N/M_Y – Reset all model settings to default
o – Lock keys until ENTER-LONG is pressed | No/Yes

## 6. Key and Display Test

This function can be used to test the display to make sure every element is working as well as all the buttons are function properly.

To start the test, turn the steering wheel left and press ENTER-LONG. As long as ENTER is pressed, all the segments on the display will be lighted. Once ENTER is released, the radio will go to the key test.

Pressing a key will display its name in the alphanumeric display. If a key is pressed and held for 1 second or longer, the key name will be displayed along with an L to the left.

Press BACK-LONG or ENTER-LONG to exit the key test.

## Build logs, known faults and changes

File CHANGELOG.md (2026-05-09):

# Changelog

## v1.0.0 (2026-xx-xx)
  - Updated code base to support Teensy 2.0 microcontroller.
  - Added support for FlySky FS-GT3B transmitter with custom firmware 0.6.1.
  - Improved balancing algorithm for better stability.
  - Added new features for remote control, including additional channels for controlling extra functions.
  - Updated documentation and pinout diagrams for the new hardware configuration.

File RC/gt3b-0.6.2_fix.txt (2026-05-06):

The problem has been solved. The major problem is the space time from 300us to 400us
Edit ppm.h, change

Set the remote to PTF mode(follow the manual) and set to 24ms(follow the manual)

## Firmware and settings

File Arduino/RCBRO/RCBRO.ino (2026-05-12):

/**
 * @file        RCBRO.ino
 *
 * @brief       RC Version of BROBOT EVO 2, the self balance robot with stepper motors by JJROBOTS.
 *
 * @details     Based on version 2.82, but with some modifications to be controlled by RC remote instead of WiFi.
 *              The code is simplified and some features are removed to make it more suitable for RC control.
 *
 * @date        08-05-2026
 * @author      Mick K
 *
 */

#include <Wire.h>

// Forward declaration needed because Arduino's auto-prototype generator
// does not preserve default parameters across .ino files.
float speedPIControl(float DT, int16_t input, int16_t setPoint, float Kp, float Ki, bool integrate = true);

// NORMAL MODE PARAMETERS (MAXIMUM SETTINGS)
#define MAX_THROTTLE 400          // Reduced for heavier 18650 pack (was 550)
#define MAX_STEERING 120
#define MAX_TARGET_ANGLE 12       // Reduced for heavier 18650 pack (was 14)

// PRO MODE = MORE AGGRESSIVE (MAXIMUM SETTINGS)
#define MAX_THROTTLE_PRO 550      // Reduced for heavier 18650 pack (was 780)
#define MAX_STEERING_PRO 240      // Max recommended value: 280
#define MAX_TARGET_ANGLE_PRO 16   // Reduced for heavier 18650 pack (was 18)

// Fall detection / raise-up thresholds
#define FALL_ANGLE 74
#define RAISEUP_ANGLE 56

#define SERVO_ARM_FLIP_ANGLE 40    // Angle threshold before the arm movement is reversed.

// Default control terms for EVO 2
#define KP 0.32
#define KD 0.050
#define KP_THROTTLE 0.080
#define KI_THROTTLE 0.1
#define KP_POSITION 0.06
#define KD_POSITION 0.45
//#define KI_POSITION 0.02

// Control gains for raiseup (the raiseup movement require special control parameters)
#define KP_RAISEUP 0.1
#define KD_RAISEUP 0.16
#define KP_THROTTLE_RAISEUP 0       // No speed control on raiseup
#define KI_THROTTLE_RAISEUP 0.0

#define MAX_CONTROL_OUTPUT 500
#define ITERM_MAX_ERROR 30          // Iterm windup constants for PI control
#define ITERM_MAX 10000

#define ANGLE_OFFSET 0.0            // Offset angle for balance (to compensate robot own weight distribution)

// Servo definitions
#define SERVO_AUX_NEUTRO 1500       // Servo neutral position
#define SERVO_MIN_PULSEWIDTH 700    // Minimum pulse width in microsecond for the servo (default: 700)
#define SERVO_MAX_PULSEWIDTH 2500   // Maximum pulse width in microsecond for the servo (default: 2500)

#define SERVO2_NEUTRO 1500

#define ZERO_SPEED 65535
#define MAX_ACCEL 14          // Maximum motor acceleration (MAX RECOMMENDED VALUE: 20) (default:14)

#define MICROSTEPPING 16      // 8 or 16 for 1/8 or 1/16 driver microstepping (default:16) A4988, all MS pins high.

#define DEBUG 0               // 0 = No debug info (default) DEBUG 1 for console output
#define DEBUG_MPU 0

// AUX definitions
#define CLR(x,y) (x&=(~(1<<y)))
#define SET(x,y) (x|=(1<<y))
#define RAD2GRAD 57.2957795

// Pins (Teensy 2.0, Arduino Leonardo Clone)
#define ENABLE_MOTORS 4

#define STEP_M1 11          // B7
#define STEP_M1_PORT PORTB
#define STEP_M1_PIN 7
#define DIR_M1  8           // B4
#define DIR_M1_PORT PORTB
#define DIR_M1_PIN 4

#define STEP_M2 12          // D6 - Also LED.
#define STEP_M2_PORT PORTD
#define STEP_M2_PIN 6
#define DIR_M2  5           // C6
#define DIR_M2_PORT PORTC
#define DIR_M2_PIN 6

#define SERVO1_PIN 10       // B6
#define SERVO2_PIN 13       // C7

#define PWM_CH1 1           // D3 (INT3)
#define PWM_CH2 0           // D2 (INT2)
#define PWM_CH3 7           // E6 (INT6)

long timer_old;
long timer_value;
float dt;

// Angle of the robot (used for stability control)
float angle_adjusted;
float angle_adjusted_Old;
float angle_adjusted_filtered = 0.0;

// Default control values from constant definitions
float Kp = KP;
float Kd = KD;
float Kp_thr = KP_THROTTLE;
float Ki_thr = KI_THROTTLE;
float Kp_user = KP;
float Kd_user = KD;
float Kp_thr_user = KP_THROTTLE;
float Ki_thr_user = KI_THROTTLE;
float Kp_position = KP_POSITION;
float Kd_position = KD_POSITION;
float PID_errorSum;
float PID_errorOld = 0;
float setPointOld = 0;
float target_angle;
int16_t throttle;
float steering;
float max_throttle = MAX_THROTTLE;
float max_steering = MAX_STEERING;
float max_target_angle = MAX_TARGET_ANGLE;
float control_output;
float angle_offset = ANGLE_OFFSET;


// Expo curve factor: 0.0 = linear, 1.0 = full expo (very soft centre)
#define EXPO_STEERING 0.5f
#define EXPO_THROTTLE 0.4f

/**
 * @brief  Apply an exponential curve to a normalised stick input.
 *         input and output are in the range [-1.0, 1.0].
 *         expo = 0 -> linear, expo = 1 -> pure cubic (maximum softness around centre).
 */
float applyExpo(float input, float expo)
{
    return input * (expo * input * input + (1.0f - expo));
}

boolean positionControlMode = false;
uint8_t mode = 0;  // mode = 0 Normal mode, mode = 1 Pro mode (More agressive)

int16_t motor1;
int16_t motor2;

// position control
volatile int32_t steps1, steps2;
int32_t target_steps1, target_steps2;
int16_t motor1_control, motor2_control;

int16_t speed_M1, speed_M2;        // Actual speed of motors
volatile int8_t dir_M1, dir_M2;    // Actual direction of steppers motors
int16_t actual_robot_speed;        // overall robot speed (measured from steppers speed)
float estimated_speed_filtered;    // Estimated robot speed

// OSC output variables (kept for potential future use)
bool startupLogPrinted = false;

uint16_t rc_ch3_us = 1500;
bool rc_ch3_wasLow = false;

/**
 * @brief     Function to print the startup banner and firmware information to the Serial console.
              This function is called once during the setup() function after the Serial connection is
              established. It prints a header with the firmware version and author information, and
              sets a flag to indicate that the startup log has been printed.
 */
void printStartupBanner()
{
    Serial.println(F(""));
    Serial.println(F("========================================"));
    Serial.println(F("  RCBRO - Startup"));
    Serial.println(F("========================================"));
    Serial.println(F("[INFO] Firmware: RCBRO v1.0.0 by Mick K"));
    startupLogPrinted = true;
}

/**
 * @brief    Arduino setup function. It is called once at the beginning of the program.
 */
void setup()
{
    // STEPPER PINS ON JJROBOTS BROBOT BRAIN BOARD
    pinMode(ENABLE_MOTORS, OUTPUT);     // ENABLE MOTORS
    pinMode(STEP_M1, OUTPUT);           // STEP MOTOR 1
    pinMode(DIR_M1, OUTPUT);            // DIR MOTOR 1
    pinMode(STEP_M2, OUTPUT);           // STEP MOTOR 2
    pinMode(DIR_M2, OUTPUT);            // DIR MOTOR 2
    digitalWrite(ENABLE_MOTORS, HIGH);  // Disable motors
    pinMode(SERVO1_PIN, OUTPUT);        // Servo1 (arm)
    pinMode(SERVO2_PIN, OUTPUT);        // Servo2 (not wired)
    pinMode(PWM_CH1, INPUT);            // PWM input from RC receiver channel 1 (steering)
    pinMode(PWM_CH2, INPUT);            // PWM input from RC receiver channel 2 (throttle)
    pinMode(PWM_CH3, INPUT);            // PWM input from RC receiver channel 3 (mode switch and arm control)

    Serial.begin(115200); // Serial output to console

    // Leonardo uses native USB; wait briefly so startup logs are not missed.
    uint32_t serialWaitStart = millis();
    while (!Serial && (millis() - serialWaitStart < 2000))
    {
    }
    if (Serial)
        printStartupBanner();

    PWM_init();
    Serial.println(F("[OK] RC PWM input initialized"));

    // Initialize I2C bus (MPU6050 is connected via I2C)
    Wire.begin();

    Serial.println(F("[OK] I2C bus initialized"));
    delay(200);
    Serial.println(F("[INFO] Hold robot still: IMU warmup/calibration..."));

#if DEBUG > 0
    delay(9000);
#else
    delay(1000);
#endif
    MPU6050_setup();  // setup MPU6050 IMU
    delay(500);

    // Calibrate gyros
    MPU6050_calibrate();

    // Init servos
    Serial.println(F("[INIT] Servos"));
    BROBOT_initServo();
    BROBOT_moveServo1(SERVO_AUX_NEUTRO);

    // STEPPER MOTORS INITIALIZATION
    Serial.println(F("[INIT] Stepper drivers/timers"));
    // MOTOR1 => TIMER1
    TCCR1A = 0;                            // Timer1 CTC mode 4, OCxA,B outputs disconnected
    TCCR1B = (1 << WGM12) | (1 << CS11);  // Prescaler=8, => 2Mhz
    OCR1A = ZERO_SPEED;                    // Motor stopped
    dir_M1 = 0;
    TCNT1 = 0;

    // MOTOR2 => TIMER3
    TCCR3A = 0;                            // Timer3 CTC mode 4, OCxA,B outputs disconnected
    TCCR3B = (1 << WGM32) | (1 << CS31);  // Prescaler=8, => 2Mhz
    OCR3A = ZERO_SPEED;                    // Motor stopped
    dir_M2 = 0;
    TCNT3 = 0;

    delay(200);

    // Enable stepper drivers and TIMER interrupts
    digitalWrite(ENABLE_MOTORS, LOW);   // Enable stepper drivers

    // Enable TIMERs interrupts
    TIMSK1 |= (1 << OCIE1A); // Enable Timer1 interrupt
    TIMSK3 |= (1 << OCIE3A); // Enable Timer3 interrupt

    // Little motor vibration and servo move to indicate that robot is ready
    for (uint8_t k = 0; k < 5; k++)
    {
        setMotorSpeed(1, 5);
        setMotorSpeed(2, 5);
        BROBOT_moveServo1(SERVO_AUX_NEUTRO + 100);
        BROBOT_moveServo2(SERVO2_NEUTRO + 100);
        delay(200);
        setMotorSpeed(1, -5);
        setMotorSpeed(2, -5);
        BROBOT_moveServo1(SERVO_AUX_NEUTRO - 100);
        BROBOT_moveServo2(SERVO2_NEUTRO - 100);
        delay(200);
    }
    BROBOT_moveServo1(SERVO_AUX_NEUTRO);
    BROBOT_moveServo2(SERVO2_NEUTRO);

    Serial.println(F("[OK] Calibration complete"));
    Serial.println(F("[READY] Control loop started"));
    timer_old = micros();
}


/**
 * @brief    Arduino loop function. It is called in a loop after setup() is finished.
 *           This is the main control loop of the robot, where the IMU data is read,
 *           calculate the control output and send commands to the motors.
 */
void loop()
{
    // If host opens Serial Monitor after boot, print startup header once when it becomes available.
    if (!startupLogPrinted && Serial)
        printStartupBanner();

    // We read the timer at the beginning of the loop to have a more accurate dt for the control loop.
    timer_value = micros();

    // We read the IMU data only when new data is available
    // (MPU6050 has a data ready flag that we check with MPU6050_newData() function).
    if (MPU6050_newData())
    {
        MPU6050_read_3axis();

        dt = (timer_value - timer_old) * 0.000001; // dt in seconds
        timer_old = timer_value;

        angle_adjusted_Old = angle_adjusted;
        // Get new orientation angle from IMU (MPU6050)
        float MPU_sensor_angle = MPU6050_getAngle(dt);
        angle_adjusted = MPU_sensor_angle + angle_offset;
        if ((MPU_sensor_angle > -15) && (MPU_sensor_angle < 15))
            angle_adjusted_filtered = angle_adjusted_filtered * 0.99 + MPU_sensor_angle * 0.01;

#if DEBUG_MPU==1
        Serial.print(dt);
        Serial.print(" ");
        Serial.print(angle_offset);
        Serial.print(" ");
        Serial.print(angle_adjusted);
        Serial.print(",");
        Serial.println(angle_adjusted_filtered);
#endif

#if DEBUG==1
        static uint32_t lastDebug = 0;
        static uint16_t imuCount = 0;

        imuCount++;

        if (millis() - lastDebug >= 1000)
        {
            Serial.print("IMU Hz: ");
            Serial.print(imuCount);
            Serial.print(" dt: ");
            Serial.println(dt, 6);

            imuCount = 0;
            lastDebug = millis();
        }

        PWM_debugPrint(100);
#endif

        // We calculate the estimated robot speed:
        // Estimated robot speed is calculated from the speed of the stepper motors,
        // which is measured from the time between steps in the TIMER interrupts.
        // We take the average of both motors as the overall robot speed.
        actual_robot_speed = (speed_M1 + speed_M2) / 2;

        float angular_velocity = (angle_adjusted - angle_adjusted_Old) * 25.0f;
        float estimated_speed = -(float)actual_robot_speed + angular_velocity;
        estimated_speed_filtered = estimated_speed_filtered * 0.9f + estimated_speed * 0.1f;

#if DEBUG==2
        Serial.print(angle_adjusted);
        Serial.print(" ");
        Serial.println(estimated_speed_filtered);
#endif

        // --- RC INPUT (CH1 = steering, CH2 = throttle) ---
        if (!positionControlMode)
        {
            uint16_t ch1 = PWM_getChannelUs(1); // 1000-2000 us, 1500 = neutral
            uint16_t ch2 = PWM_getChannelUs(2);
            uint16_t ch3 = PWM_getChannelUs(3); // arm trigger
            rc_ch3_us = ch3;

            // PRO mode toggle: rising edge of CH3 going LOW (<= 1200 us)
            bool ch3IsLow = (ch3 <= 1200);
            if (ch3IsLow && !rc_ch3_wasLow)
            {
                mode = (mode == 0) ? 1 : 0; // toggle between normal(0) and pro(1)
                if (mode == 1)
                {
                    max_throttle     = MAX_THROTTLE_PRO;
                    max_steering     = MAX_STEERING_PRO;
                    max_target_angle = MAX_TARGET_ANGLE_PRO;
                    Kp_user          = KP;
                    Kd_user          = KD;
                    Serial.println(F("[MODE] PRO"));
                }
                else
                {
                    max_throttle     = MAX_THROTTLE;
                    max_steering     = MAX_STEERING;
                    max_target_angle = MAX_TARGET_ANGLE;
                    Kp_user          = KP;
                    Kd_user          = KD;
                    Serial.println(F("[MODE] NORMAL"));
                }
            }
            rc_ch3_wasLow = ch3IsLow;

            // Apply dead-band around neutral (1500 us) to avoid drift
            if (abs((int)ch1 - 1500) < 30) ch1 = 1500;
            if (abs((int)ch2 - 1500) < 30) ch2 = 1500;

            // CH1 = steering, CH2 = throttle
            // Clamp and map from PWM input range (1000-2000 us) to control output range (-max, max)
            steering = map(ch1, 1000, 2000, -max_steering, max_steering);
            throttle = map(ch2, 1000, 2000, -max_throttle, max_throttle);

            // Apply expo curve (soften centre feel)
            steering = applyExpo(steering / max_steering, EXPO_STEERING) * max_steering;
            throttle = applyExpo(throttle / max_throttle, EXPO_THROTTLE) * max_throttle;
        }

        if (positionControlMode)
        {
            // POSITION CONTROL. INPUT: Target steps for each motor. Output: motors speed
            motor1_control = positionPDControl(steps1, target_steps1, Kp_position, Kd_position, speed_M1);
            motor2_control = positionPDControl(steps2, target_steps2, Kp_position, Kd_position, speed_M2);

            // Convert from motor position control to throttle / steering commands
            throttle = (motor1_control + motor2_control) / 2;
            throttle = constrain(throttle, -190, 190);
            steering = motor2_control - motor1_control;
            steering = constrain(steering, -50, 50);
        }

        // ROBOT SPEED CONTROL: This is a PI controller.
        //    input:user throttle(robot speed), variable: estimated robot speed, output: target robot angle to get the desired speed
        //    Anti-windup: freeze the speed I-term when either:
        //      1) speed loop output (target_angle) was saturated, or
        //      2) inner balance loop is near motor authority limit.
        //    This avoids runaway at high speed where more I-term cannot produce more wheel torque.
        {
            static bool speed_pi_saturated = false;
            bool balance_loop_saturated = (abs((int)control_output) > (MAX_CONTROL_OUTPUT - 40));
            bool allow_speed_i = (!speed_pi_saturated) && (!balance_loop_saturated);

            target_angle = speedPIControl(dt, estimated_speed_filtered, throttle, Kp_thr, Ki_thr, allow_speed_i);
            float target_angle_clamped = constrain(target_angle, -max_target_angle, max_target_angle);
            speed_pi_saturated = (target_angle != target_angle_clamped);
            target_angle = target_angle_clamped;
        }

#if DEBUG==3
        Serial.print(angle_adjusted);
        Serial.print(" ");
        Serial.print(estimated_speed_filtered);
        Serial.print(" ");
        Serial.println(target_angle);
#endif

        // Stability control (100Hz loop): This is a PD controller.
        //    input: robot target angle(from SPEED CONTROL), variable: robot angle, output: Motor speed
        //    We integrate the output (sumatory), so the output is really the motor acceleration, not motor speed.
        control_output += stabilityPDControl(dt, angle_adjusted, target_angle, Kp, Kd);

        control_output = constrain(control_output, -MAX_CONTROL_OUTPUT, MAX_CONTROL_OUTPUT); // Limit max output from control

        // The steering part from the user is injected directly to the output
        motor1 = control_output + steering;
        motor2 = control_output - steering;

        // Limit max speed (control output)
        motor1 = constrain(motor1, -MAX_CONTROL_OUTPUT, MAX_CONTROL_OUTPUT);
        motor2 = constrain(motor2, -MAX_CONTROL_OUTPUT, MAX_CONTROL_OUTPUT);

        int angle_ready = FALL_ANGLE;

        if ((abs(angle_adjusted) < angle_ready))
        {
            // NORMAL MODE
            digitalWrite(ENABLE_MOTORS, LOW);  // Motors enable
            // NOW we send the commands to the motors
            setMotorSpeed(1, motor1);
            setMotorSpeed(2, motor2);
        }
        else   // Robot not ready (flat), angle > angle_ready => ROBOT OFF
        {
            digitalWrite(ENABLE_MOTORS, HIGH);  // Disable motors
            setMotorSpeed(1, 0);
            setMotorSpeed(2, 0);
            PID_errorSum = 0;  // Reset PID I term
            Kp = KP_RAISEUP;   // CONTROL GAINS FOR RAISE UP
            Kd = KD_RAISEUP;
            Kp_thr = KP_THROTTLE_RAISEUP;
            Ki_thr = KI_THROTTLE_RAISEUP;
            // RESET steps
            steps1 = 0;
            steps2 = 0;
            positionControlMode = false;
            throttle = 0;
            steering = 0;
        }

        // Servo1 arm: CH3 high (>=1800 us) triggers the arm.
        // Forward when upright, backward when robot is on its back.
        if (rc_ch3_us >= 1800)
        {
            // If the robot is tilted more than 40 degrees,
            // we consider it is on its back and we move the arm backward to help it raise up.
            if (angle_adjusted > SERVO_ARM_FLIP_ANGLE) {
                BROBOT_moveServo1(SERVO_MAX_PULSEWIDTH);
            }
            // If the robot is tilted less than 40 degrees,
            // we consider it is upright and we move the arm forward to help it balance.
            else {
                BROBOT_moveServo1(SERVO_MIN_PULSEWIDTH);
            }

        }
        else
            BROBOT_moveServo1(SERVO_AUX_NEUTRO);

        // Servo2 - hold at neutral (no RC channel assigned yet)
        BROBOT_moveServo2(SERVO2_NEUTRO);

        // Normal condition?
        if (abs(angle_adjusted) < RAISEUP_ANGLE)
        {
            Kp = Kp_user;            // Default user control gains
            Kd = Kd_user;
            Kp_thr = Kp_thr_user;
            Ki_thr = Ki_thr_user;
        }
        else    // We are in the raise up procedure => we use special control parameters
        {
            Kp = KP_RAISEUP;         // CONTROL GAINS FOR RAISE UP
            Kd = KD_RAISEUP;
            Kp_thr = KP_THROTTLE_RAISEUP;
            Ki_thr = KI_THROTTLE_RAISEUP;
        }

    } // End of new IMU data
}

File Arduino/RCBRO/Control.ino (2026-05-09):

/**
 * @file        Control.ino
 *
 * @brief       Control functions for BROBOT EVO 2, the self balance robot with stepper motors by JJROBOTS.
 *
 * @details     This file contains the implementation of the control algorithms for the robot, including the PD
 *              controller for balance and the PI controller for speed control. It also includes the interrupt
 *              service routines for the stepper motor control and the function to set the motor speed.
 *
 * @date        08-05-2026
 * @author      Mick K
 *
 */

#include <util/atomic.h>

/**
 * @brief     Stability control function. This is a PD controller that calculates the control output based on the current angle and the target angle.
 * @param     DT          Time step in seconds.
 * @param     input       Current angle of the robot (measured by the IMU).
 * @param     setPoint    Target angle for the robot to achieve (calculated by the speed PI controller).
 * @param     Kp          Proportional gain for the PD controller.
 * @param     Kd          Derivative gain for the PD controller.
 * @return    Control output for the motors to achieve the desired angle.
 */
float stabilityPDControl(float DT, float input, float setPoint, float Kp, float Kd)
{
    if (DT <= 0.0f)
        return 0.0f;

    float error = setPoint - input;

    float Kd_setPoint = constrain((setPoint - setPointOld), -8.0f, 8.0f);
    float inv_DT = 1.0f / DT;

    float output = Kp * error + Kd * (Kd_setPoint - (input - PID_errorOld)) * inv_DT;

    PID_errorOld = input;
    setPointOld = setPoint;

    return output;
}


/**
 * @brief     Speed control function. This is a PI controller that calculates the target angle for the robot to achieve the desired speed.
 * @param     DT          Time step in seconds.
 * @param     input       Current estimated speed of the robot (calculated from the stepper motors speed and the IMU angle).
 * @param     setPoint    Desired speed for the robot (from user throttle input).
 * @param     Kp          Proportional gain for the PI controller.
 * @param     Ki          Integral gain for the PI controller.
 * @param     integrate   If false, the I-term is frozen (anti-windup clamped integration).
 * @return    Target angle for the robot to achieve the desired speed.
 */
float speedPIControl(float DT, int16_t input, int16_t setPoint, float Kp, float Ki, bool integrate = true)
{
    if (DT <= 0.0f)
        return 0.0f;

    int16_t error = setPoint - input;

    if (integrate)
    {
        float limitedError = constrain((float)error, -ITERM_MAX_ERROR, ITERM_MAX_ERROR);
        PID_errorSum += limitedError * DT;
        PID_errorSum = constrain(PID_errorSum, -ITERM_MAX, ITERM_MAX);
    }

    return Kp * error + Ki * PID_errorSum;
}

/**
 * @brief     Position control function. This is a PD controller that calculates the motor control output based on the current position and the target position.
 * @param     actualPos      Current position of the motor (measured in steps).
 * @param     setPointPos    Desired position for the motor (measured in steps).
 * @param     Kpp            Proportional gain for the position control.
 * @param     Kdp            Derivative gain for the position control.
 * @param     speedM         Current speed of the motor (measured in steps per second).
 * @return    Control output for the motor to achieve the desired position.
 */
float positionPDControl(long actualPos, long setPointPos, float Kpp, float Kdp, int16_t speedM)
{
    float P = constrain(Kpp * (float)(setPointPos - actualPos), -115.0f, 115.0f);

    // Damping should usually oppose movement.
    // If your robot reacts backwards, change '-' back to '+'.
    return P - Kdp * (float)speedM;
}

/**
 * @brief     Interrupt Service Routine for TIMER 1 Compare Match A. This ISR is responsible for controlling the stepper motor 1 speed and direction.
 *            It is triggered at a frequency determined by the OCR1A register, which is set by the setMotorSpeed function.
 *            The ISR sets the STEP pin for motor 1 to generate a step pulse, and updates the steps count based on the direction of the motor.
 */
ISR(TIMER1_COMPA_vect)
{
    if (dir_M1 == 0)
        return;

    SET(STEP_M1_PORT, STEP_M1_PIN);

    // Minimum STEP high pulse width for stepper driver
    asm volatile(
        "nop\nnop\nnop\nnop\n"
        "nop\nnop\nnop\nnop\n"
    );

    CLR(STEP_M1_PORT, STEP_M1_PIN);

    if (dir_M1 > 0)
        steps1--;
    else
        steps1++;
}

/**
 * @brief     Interrupt Service Routine for TIMER 3 Compare Match A. This ISR is responsible for controlling the stepper motor 2 speed and direction.
 *            It is triggered at a frequency determined by the OCR3A register, which is set by the setMotorSpeed function.
 *            The ISR sets the STEP pin for motor 2 to generate a step pulse, and updates the steps count based on the direction of the motor.
 */
ISR(TIMER3_COMPA_vect)
{
    if (dir_M2 == 0)
        return;

    SET(STEP_M2_PORT, STEP_M2_PIN);

    // Minimum STEP high pulse width for stepper driver
    asm volatile(
        "nop\nnop\nnop\nnop\n"
        "nop\nnop\nnop\nnop\n"
    );

    CLR(STEP_M2_PORT, STEP_M2_PIN);

    if (dir_M2 > 0)
        steps2--;
    else
        steps2++;
}

/**
 * @brief     Function to set the speed of the motors. This function takes a desired speed for the motor, applies
 *            acceleration limits, and updates the timer period and direction for the motor control.
 * @param     motorNum   Motor number (1 or 2) to set the speed for.
 * @param     tspeed     Desired speed for the motor (in steps per second). Positive values for forward, negative for backward, and zero for stop.
 */
void setMotorSpeed(uint8_t motorNum, int16_t tspeed)
{
    int32_t speed;
    int32_t timer_period;

    int16_t         &speed_M = (motorNum == 1) ? speed_M1 : speed_M2;
    volatile int8_t &dir_M   = (motorNum == 1) ? dir_M1   : dir_M2;

    // Limit motor acceleration
    if ((speed_M - tspeed) > MAX_ACCEL)
        speed_M -= MAX_ACCEL;
    else if ((speed_M - tspeed) < -MAX_ACCEL)
        speed_M += MAX_ACCEL;
    else
        speed_M = tspeed;
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

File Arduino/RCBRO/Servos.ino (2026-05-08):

/**
 * @file        Servos.ino
 *
 * @brief       Servo control code for BROBOT EVO 2, the self balance robot with stepper motors by JJROBOTS.
 *              This file contains the definitions and functions to initialize and control the servos used for
 *              steering and throttle control of the robot.
 *
 * @details     The servos are controlled using Timer4 on the Arduino Leonardo board, which allows for precise PWM
 *              control with a resolution of 11 bits. The functions provided in this file allow for initializing the
 *              servo control and setting the PWM values for two servos, which can be used for various purposes such
 *              as steering and throttle control. The PWM values are constrained to the defined minimum and maximum
 *              pulse widths to ensure safe operation of the servos. The code is based on the standard Arduino Servo
 *              library, but with custom implementation to allow for more precise control and to avoid conflicts with
 *              the stepper motor control which uses Timer1 and Timer3. The servos are connected to specific pins on
 *              the Leonardo board (Pin10 for Servo1 and Pin13 for Servo2), and the Timer4 is configured to generate
 *              the appropriate PWM signals for these pins. The code is designed to be efficient and to minimize the
 *              impact on the main control loop of the robot, allowing for smooth and responsive control of the servos
 *              while maintaining the stability and performance of the robot.
 *
 * @date        08-05-2026
 * @author      Mick K
 *
 */

// Default servo definitions
#define SERVO1_AUX_NEUTRO 1500  // Servo neutral position
#define SERVO1_MIN_PULSEWIDTH 700
#define SERVO1_MAX_PULSEWIDTH 2300
#define SERVO2_AUX_NEUTRO 1500  // Servo neutral position
#define SERVO2_MIN_PULSEWIDTH 700
#define SERVO2_MAX_PULSEWIDTH 2300

/**
 * @brief     Function to initialize the servo control using Timer4. This function configures Timer4 for Fast PWM mode,
 *            sets the appropriate prescaler, and configures the output pins for the servos. It also sets the initial
 *            PWM values for the servos to their neutral positions.
 */
void BROBOT_initServo()
{
    int temp;

    // Initialize Timer4 as Fast PWM
    TCCR4A = (1<<PWM4A)|(1<<PWM4B);
    TCCR4B = 0;
    TCCR4C = (1<<PWM4D);
    TCCR4D = 0;
    TCCR4E = (1<<ENHC4); // Enhaced -> 11 bits

    temp = 1500>>3;
    TC4H = temp >> 8;
    OCR4B = temp & 0xff;

    // Reset timer
    TC4H = 0;
    TCNT4 = 0;

    // Set TOP to 1023 (10 bit timer)
    TC4H = 3;
    OCR4C = 0xFF;

    // OC4A = PC7 (Pin13)  OC4B = PB6 (Pin10)   OC4D = PD7 (Pin6)
    // Set pins as outputs
    DDRB |= (1 << 6);  // OC4B = PB6 (Pin10 on Leonardo board)
    DDRC |= (1 << 7);  // OC4A = PC7 (Pin13 on Leonardo board)
    DDRD |= (1 << 7);  // OC4D = PD7 (Pin6 on Leonardo board)

    // Enable OC4A and OC4B and OCR4D output
    TCCR4A |= (1<<COM4B1)|(1<<COM4A1);
    TCCR4C |= (1<<COM4D1);
    // set prescaler to 256 and enable timer    16Mhz/256/1024 = 61Hz (16.3ms)
    TCCR4B = (1 << CS43)|(1 << CS40);
}

/**
 * @brief     Function to set the PWM value for Servo1. This function takes a desired PWM value, constrains it to the defined
 *            minimum and maximum pulse widths, and updates the Timer4 registers to generate the appropriate PWM signal for
 *            Servo1. The PWM value is shifted right by 3 to account for the resolution of Timer4 (8us steps), and the 11-bit
 *            value is split between the TC4H register (for the 3 most significant bits) and the OCR4B register (for the 8 least
 *            significant bits).
 * @param     pwm Desired PWM value for Servo1 (in microseconds). This value will be constrained to the defined minimum and maximum pulse widths.
 */
void BROBOT_moveServo1(int pwm)
{
    pwm = constrain(pwm, SERVO1_MIN_PULSEWIDTH, SERVO1_MAX_PULSEWIDTH) >> 3;  // Check max values and Resolution: 8us
    // 11 bits => 3 MSB bits on TC4H, LSB bits on OCR4B
    TC4H = pwm >> 8;
    OCR4B = pwm & 0xFF;
}

/**
 * @brief     Function to set the PWM value for Servo2. This function takes a desired PWM value, constrains it to the defined
 *            minimum and maximum pulse widths, and updates the Timer4 registers to generate the appropriate PWM signal for
 *            Servo2. The PWM value is shifted right by 3 to account for the resolution of Timer4 (8us steps), and the 11-bit
 *            value is split between the TC4H register (for the 3 most significant bits) and the OCR4A and OCR4D registers (for the 8 least
 *            significant bits). The function updates both OCR4A and OCR4D to support different board versions where Servo2 may be connected to either Pin13 or Pin6.
 * @param     pwm Desired PWM value for Servo2 (in microseconds). This value will be constrained to the defined minimum and maximum pulse widths.
 */
void BROBOT_moveServo2(int pwm)
{
    pwm = constrain(pwm, SERVO2_MIN_PULSEWIDTH, SERVO2_MAX_PULSEWIDTH) >> 3;  // Check max values and Resolution: 8us
    // 11 bits => 3 MSB bits on TC4H, LSB bits on OCR4B
    TC4H = pwm >> 8;
    OCR4A = pwm & 0xFF;  // 2.0 or 2.3  boards servo2 output
    OCR4D = pwm & 0xFF;  // 2.1 or 2.4  boards servo2 output
}

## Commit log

2026-05-06 Some RC work
    [Electronics_Shelf.STL]
2026-05-08 Add some PWM pins
2026-05-08 Optimize print outs
2026-05-11 Fix raise stability bug
    [RCBRO.ino]
2026-05-12 Fix arm inversion
2026-05-12 image and arm stl
    [Arm.STL]
